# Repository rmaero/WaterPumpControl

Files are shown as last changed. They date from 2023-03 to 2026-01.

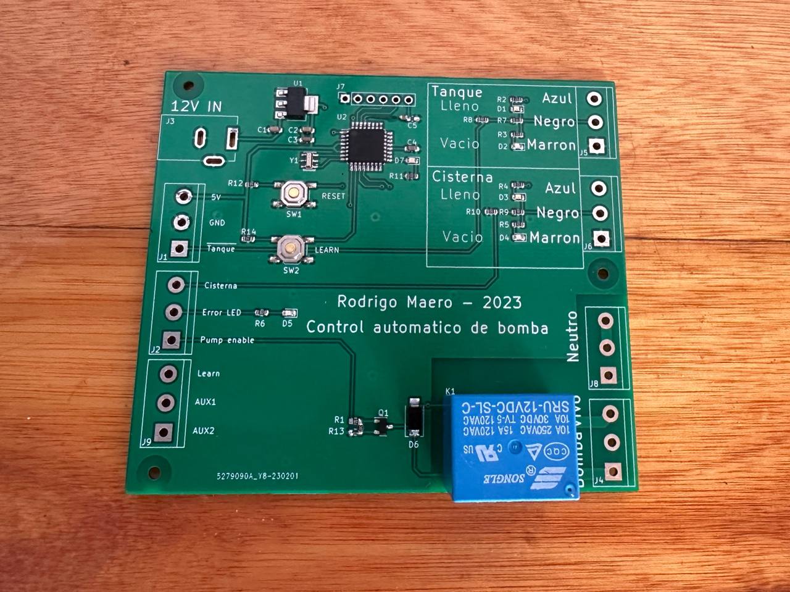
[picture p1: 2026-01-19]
Kicad/PCB_finished.jpg

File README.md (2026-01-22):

Water Pump Controller
Sistema de control automático para bombas de agua en instalaciones residenciales con cisterna y tanque elevado. Diseñado para optimizar el consumo energético y prevenir funcionamiento en seco de la bomba. La version mas actual del firmware es "MEF_IF_EEPROM".



Video demostracion
https://youtu.be/jwLdcLJ9unM

Sistema en producción implementado desde 2023

Estado: En Producción
Operando continuamente desde 2023 sin fallas en instalación residencial real.
REV. B: corregido invertidos pines Rx y Tx, resistencia pulldown de Q1. Agregado conector J10 para programar bootloader (no implementado todavia).

Problema que Resuelve
En sistemas tradicionales de cisterna + tanque elevado, las bombas funcionan con controles manuales, niveles flotantes o temporizadores simples, lo que genera:

Riesgo de funcionamiento en seco (daño a la bomba) en caso de que un sensor falle.
Desperdicio energético (bomba funcionando innecesariamente)
Falta de monitoreo del estado del sistema

Este controlador automatiza completamente el proceso con lógica inteligente. Brinda testigos luminicos para relevar el estado del tanque y de la cisterna (muy util tambien para verificar si los sensores estan funcionando correctamente en caso de aviso de falla).

Características
Hardware

Diseño de PCB custom con microcontrolador ATmega328.
Sensores de nivel de agua en cisterna y tanque
Relé para control de bomba (220V/15A)
Protección contra funcionamiento en seco
Indicadores LED de estado
Posibilidad de usar la placa como standalone sin microcontrolador integrado, sino conectandolo atraves de pines provistos en el etremo izquierdo. Facilidad para usar un ESP32 por ejemplo.

Firmware

Lógica de histéresis para evitar ciclos cortos
Protección multi-nivel:

Detección de cisterna vacía
Timeout de seguridad

Funcionamiento
Lógica básica:

Sensor detecta nivel bajo en tanque y nivel alto en cisterna → activa bomba
Sensor verifica nivel suficiente en cisterna
Bomba llena tanque hasta nivel alto
Sistema entra en standby hasta próximo ciclo

Proteccion contra funcionamiento en seco:
Por defecto, dado el caso para el que se diseñó este circuito, el tanque tiene una capacidad muy superior a la cisterna y la bomba es capaz de vaciar la cisterna en 2:15 minutos. Por lo cual se implementó un timeout que si a los 3 minutos el sensor de la cisterna no está en bajo, asume que es por falla del sensor, apaga la bomba y se queda en estado de ERROR con led rojo parpadeando

Funcion LEARN:
se puede programar que el sistema aprenda de forma automatica cuanto tiempo demora en vaciarse la cisterna. Para esto se debe tener el tanque completamente vacio y la cisterna completamente llena. Con la placa desenergizada, mantener apretado el pulsador "LEARN" y energizar la placa. Una vez que se haya encendido la bomba se puede soltar el pulsador. En este estado el microcontrolador contará el tiempo que demore en vaciarse la cisterna y lo guardará en memoria no volatil (por lo que se puede reiniciar o apagar sin problemas, el tiempo queda guardado). Asi podremos usar la proteccion contra funcionamiento en seco de forma adecuada sin necesidad de cronometrar y reprogramar el micrcocontrolador.

Especificaciones Técnicas

Microcontrolador      ATmega328
Sensores              Tipo: flotantes
Relé                  220V 15A
Alimentación          12V DC 1A
PCB                   2 capas. Dimensiones: 100mm x 80mm. 

Galería
PCB Diseñado

Instalación Real


Requisitos de Hardware

Fuente de alimentación 12V 1A
Sensores de nivel tipo flotante de 3 cables.
Cableado eléctrico certificado para bomba.

Instalación

Montar sensores en cisterna y tanque. Ajustar niveles de la misma forma que en un sistema normal.
Conectar los 3 cables de cada sensor a su correspondiente borne en la PCB.
Verificar alimentando la PCB que las luces testigo esten correctas simulando sobre los sensores manualmente que esta "lleno" o "vacio".
Conectar bomba al relé del controlador.
Alimentar el sistema.
De ser necesario, realizar la rutina de entrenamiento LEARN para calcular y calibrar el tiempo de vaciado de la cisterna.

Resultados en Producción
Desde Marzo 2023:

-Cero fallas de hardware
-Cero activaciones de funcionamiento en seco

Desarrollo Futuro (Versión Comercial)
Mejoras planificadas para siguiente versión de producto:

 Conectividad WiFi para monitoreo remoto
 App móvil para visualización de estado
 Data logging de consumo y ciclos
 Múltiples perfiles de configuración
 Carcasa plástica para montaje industrial
 Certificación eléctrica

 Consideraciones de Seguridad
⚠️ ADVERTENCIA: Este sistema maneja voltaje de red (220V). 

La instalación debe ser realizada por electricista 
Cumplir normativa eléctrica local
Incluir protección térmica en línea de bomba

Licencia
GPL V3

✉️ Contacto
Rodrigo Maero - r.maero@gmail.com
Proyecto personal desarrollado en Rosario, Argentina.

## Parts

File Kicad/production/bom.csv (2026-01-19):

Designator | Footprint | Quantity | Value | LCSC Part #
C1 | 0603 | 1 | 10uF 16V
C2 | 0603 | 1 | 10uF 16V
C3 | 0603 | 1 | 0.1uF 6.3V
C4 | 0603 | 1 | 0.1uF 6.3V
C5 | 0603 | 1 | 0.1uF 6.3V
D1 | 0603 | 1 | LED Green 0603
D2 | 0603 | 1 | LED Red 0603
D3 | 0603 | 1 | LED Green 0603
D4 | 0603 | 1 | LED Red 0603
D5 | 0603 | 1 | LED Red 0603
D6 | D_SMA | 1 | DIODE SS54 SMA
D7 | 0603 | 1 | LED Yellow
H1, H2, H3 | MountingHole_3.2mm_M3 | 3 | MountingHole
J1, J2, J4, J5, J6, J8, J9 | TerminalBlock_bornier-3_P5.08mm | 7 | Screw_Terminal_01x03
J3 | BarrelJack_Kycon_KLDX-0202-xC_Horizontal | 1 | Barrel_Jack_Switch
J7 | PinSocket_1x06_P2.54mm_Vertical | 1 | Conn_01x06_Male
JP1, JP2, JP3, JP4, JP5, JP6, JP7 | SolderJumper-2_P1.3mm_Bridged2Bar_RoundedPad1.0x1.5mm | 7 | Jumper_2_Bridged
K1 | Relay_SPDT_Finder_36.11 | 1 | 12VDC SPDT RELAY SRU-12VDC-SL-C
Q1 | SOT-23 | 1 | 2N7002
R1 | 0603 | 1 | 1k
R10 | 0603 | 1 | 1M
R11 | 0603 | 1 | 330
R12 | 0603 | 1 | 10k
R13 | 0603 | 1 | 10k
R14 | 0603 | 1 | 10k
R2 | 0603 | 1 | 470
R3 | 0603 | 1 | 470
R4 | 0603 | 1 | 470
R5 | 0603 | 1 | 470
R6 | 0603 | 1 | 330
R7 | 0603 | 1 | 1.5M
R8 | 0603 | 1 | 1M
R9 | 0603 | 1 | 1.5M
SW1, SW2 | SW_SPST_TL3342 | 2 | SW_SPST
U1 | SOT-223-3_TabPin2 | 1 | AMS1117-5.0
U2 | TQFP-32_7x7mm_P0.8mm | 1 | ATmega328P-A
Y1 | Resonator_SMD_Murata_CSTxExxV-3Pin_3.0x1.1mm_HandSoldering | 1 | Crystal 16 MHz SMD

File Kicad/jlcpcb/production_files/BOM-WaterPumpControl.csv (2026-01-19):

Comment | Designator | Footprint | LCSC
2N7002H | Q1 | SOT-23
Screw_Terminal_01x03 | J4 | TerminalBlock_bornier-3_P5.08mm
LED Red 0603 | D5 | LED_0603_1608Metric
LED Red 0603 | D2 | LED_0603_1608Metric
1k | R1 | R_0603_1608Metric
LED Green 0603 | D3 | LED_0603_1608Metric
470 | R3 | R_0603_1608Metric
10uF 16V | C1 | C_0603_1608Metric_Pad1.08x0.95mm_HandSolder
AP1117-50 | U1 | SOT-223-3_TabPin2
Screw_Terminal_01x03 | J5 | TerminalBlock_bornier-3_P5.08mm
Barrel_Jack_Switch | J3 | BarrelJack_Kycon_KLDX-0202-xC_Horizontal
Screw_Terminal_01x03 | J1 | TerminalBlock_bornier-3_P5.08mm
1.5M | R7 | R_0603_1608Metric
LED Red 0603 | D4 | LED_0603_1608Metric
470 | R5 | R_0603_1608Metric
1.5M | R9 | R_0603_1608Metric
470 | R4 | R_0603_1608Metric
10uF 16V | C2 | C_0603_1608Metric_Pad1.08x0.95mm_HandSolder
LED Green 0603 | D1 | LED_0603_1608Metric
470 | R2 | R_0603_1608Metric
330 | R6 | R_0603_1608Metric
12VDC SPDT RELAY SRU-12VDC-SL-C | K1 | Relay_SPDT_Finder_36.11
Screw_Terminal_01x03 | J2 | TerminalBlock_bornier-3_P5.08mm
1M | R10 | R_0603_1608Metric
DIODE SS54 | D6 | D_1206_3216Metric
1M | R8 | R_0603_1608Metric
Screw_Terminal_01x03 | J6 | TerminalBlock_bornier-3_P5.08mm
Screw_Terminal_01x03 | J8 | TerminalBlock_bornier-3_P5.08mm
10k | R13 | R_0603_1608Metric
Crystal_GND2 | Y1 | Resonator_SMD_Murata_CSTxExxV-3Pin_3.0x1.1mm_HandSoldering
10k | R12 | R_0603_1608Metric
0.1uF 6.3V | C3 | C_0603_1608Metric_Pad1.08x0.95mm_HandSolder
330 | R11 | R_0603_1608Metric
ATmega328P-A | U2 | TQFP-32_7x7mm_P0.8mm
Conn_01x06_Male | J7 | PinSocket_1x06_P2.54mm_Vertical
0.1uF 6.3V | C5 | C_0603_1608Metric_Pad1.08x0.95mm_HandSolder
SW_SPST | SW1 | SW_SPST_B3S-1000
LED Yellow | D7 | LED_0603_1608Metric
0.1uF 6.3V | C4 | C_0603_1608Metric_Pad1.08x0.95mm_HandSolder
Jumper_2_Bridged | JP3 | SolderJumper-2_P1.3mm_Bridged2Bar_RoundedPad1.0x1.5mm
Jumper_2_Bridged | JP2 | SolderJumper-2_P1.3mm_Bridged2Bar_RoundedPad1.0x1.5mm
Jumper_2_Bridged | JP1 | SolderJumper-2_P1.3mm_Bridged2Bar_RoundedPad1.0x1.5mm
Jumper_2_Bridged | JP4 | SolderJumper-2_P1.3mm_Bridged2Bar_RoundedPad1.0x1.5mm
Screw_Terminal_01x03 | J9 | TerminalBlock_bornier-3_P5.08mm
SW_SPST | SW2 | SW_SPST_B3S-1000
Jumper_2_Bridged | JP6 | SolderJumper-2_P1.3mm_Bridged2Bar_RoundedPad1.0x1.5mm
Jumper_2_Bridged | JP7 | SolderJumper-2_P1.3mm_Bridged2Bar_RoundedPad1.0x1.5mm
Jumper_2_Bridged | JP5 | SolderJumper-2_P1.3mm_Bridged2Bar_RoundedPad1.0x1.5mm

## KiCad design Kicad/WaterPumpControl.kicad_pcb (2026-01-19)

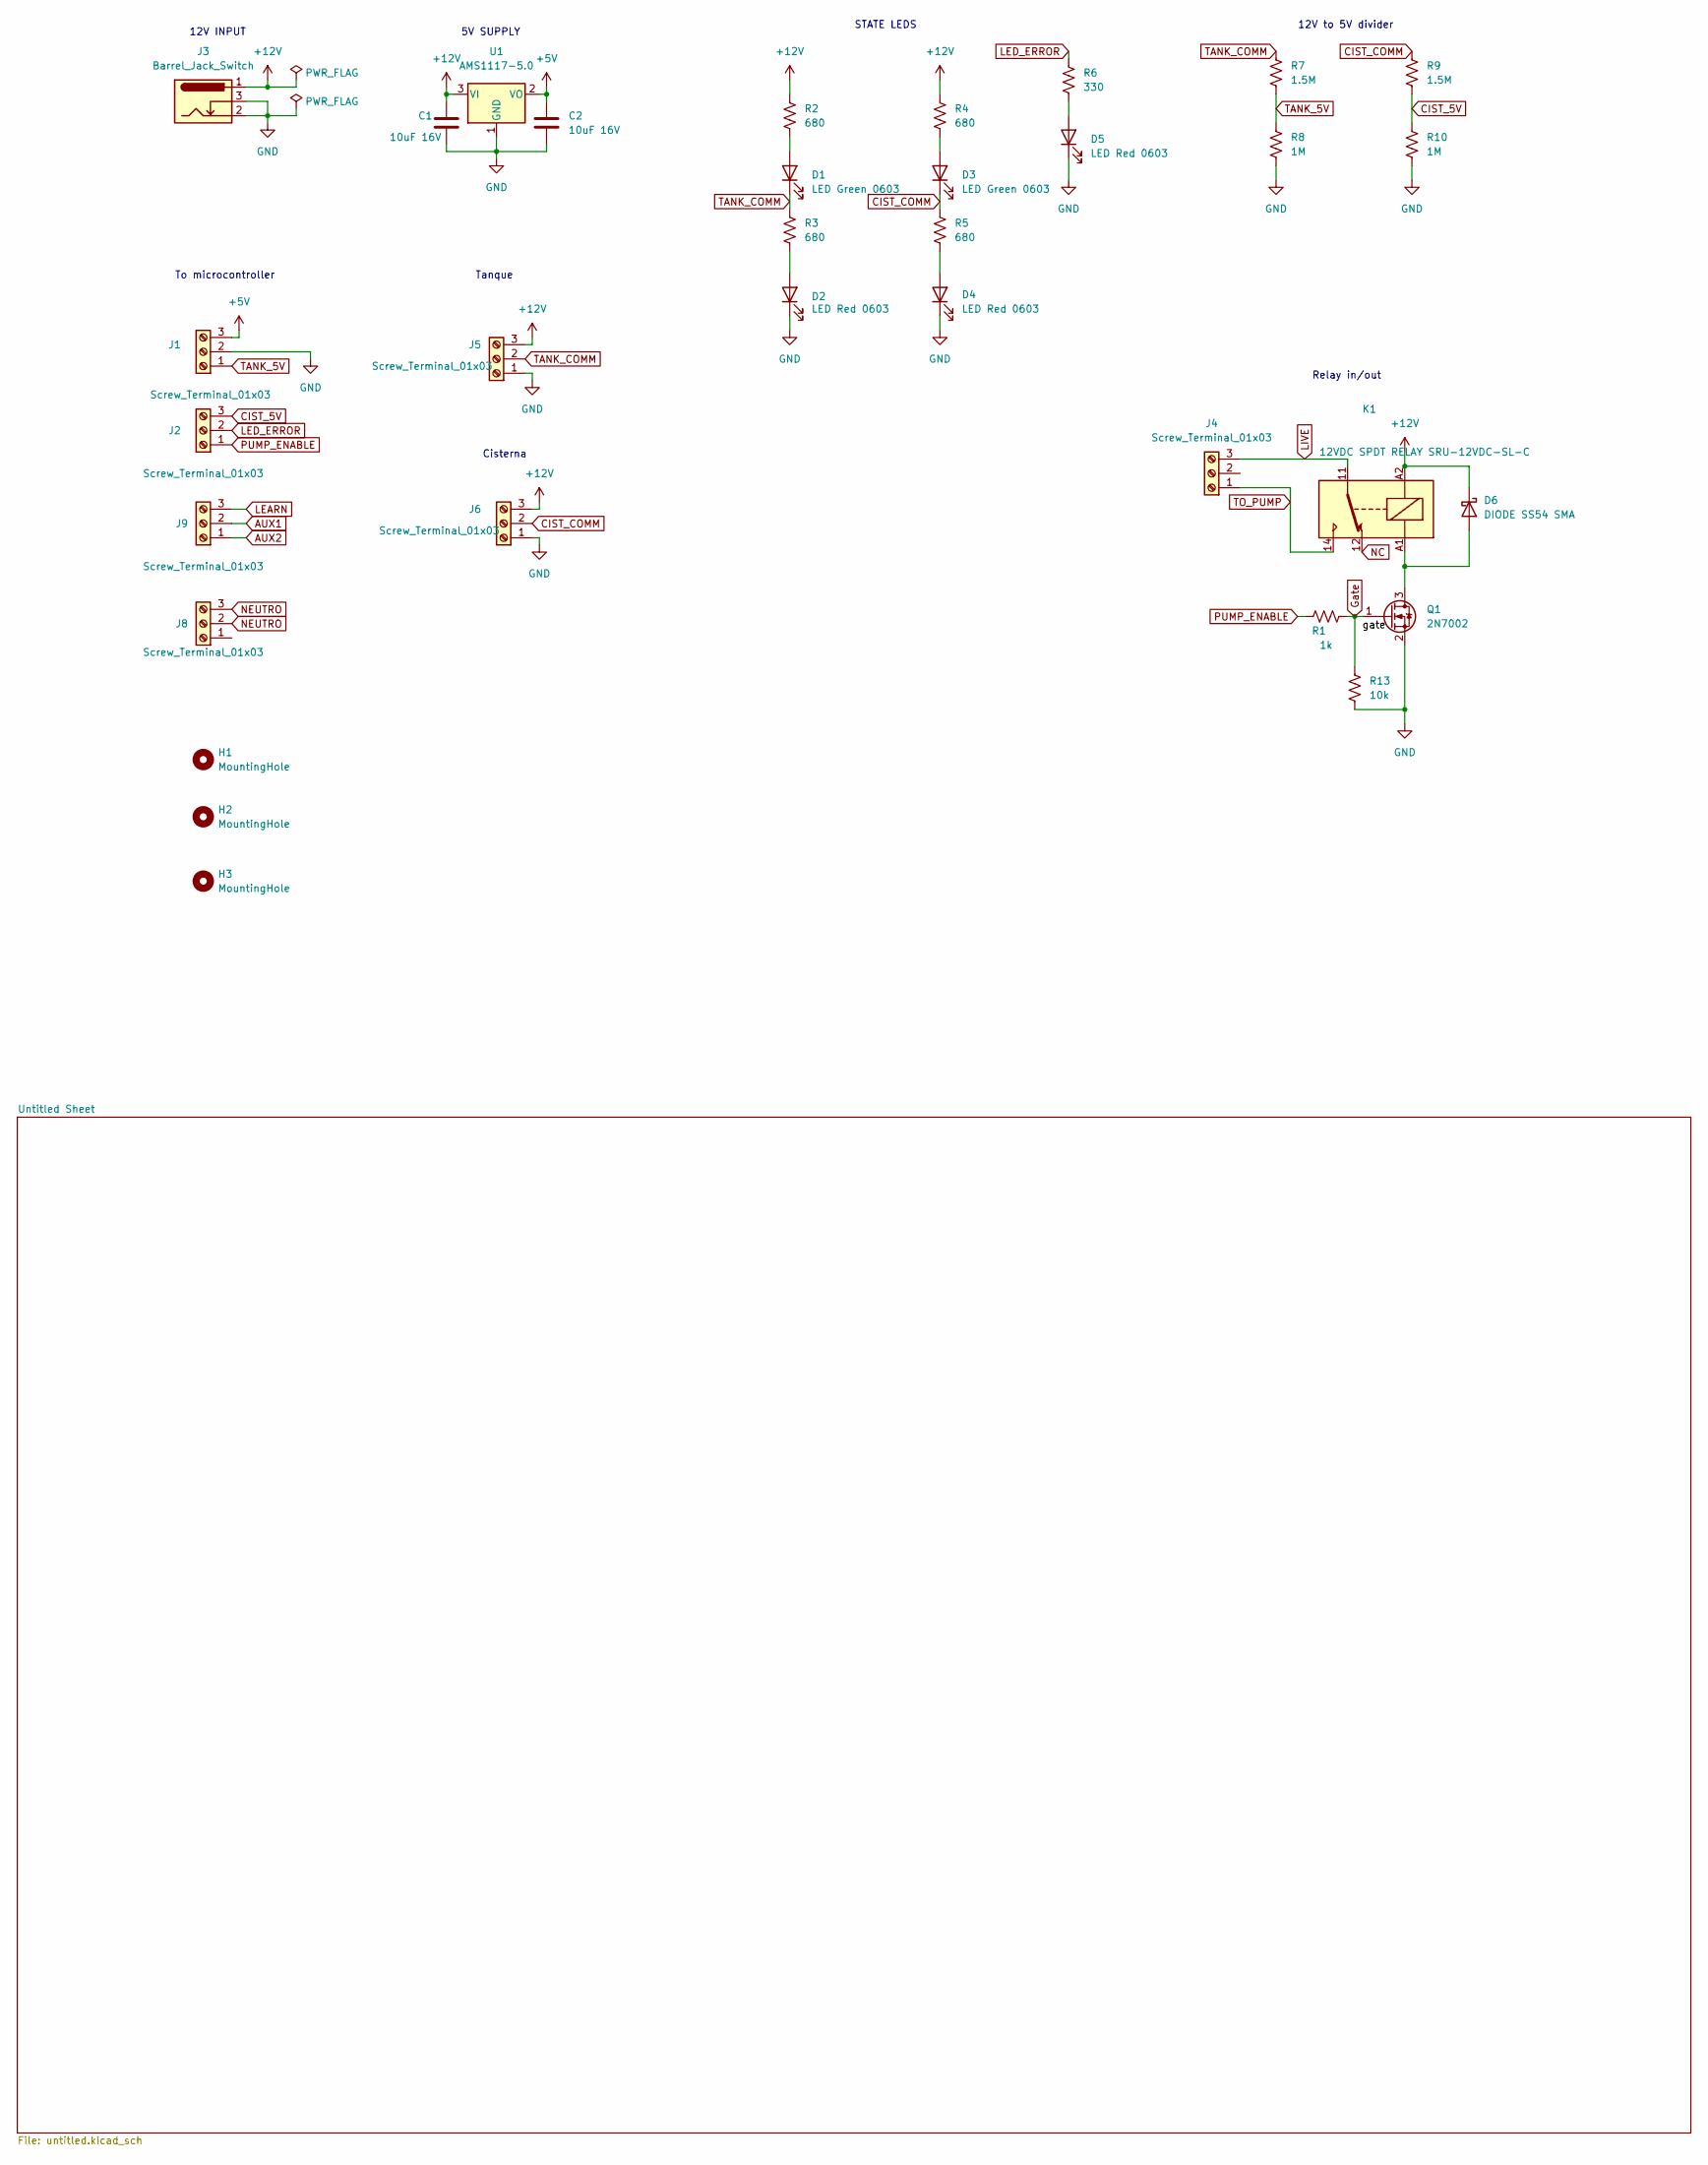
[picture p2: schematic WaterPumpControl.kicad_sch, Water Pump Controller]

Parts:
C1, C2: 10uF 16V; C_0603_1608Metric_Pad1.08x0.95mm_HandSolder
D1, D3: LED Green 0603; LED_0603_1608Metric
D2, D4, D5: LED Red 0603; LED_0603_1608Metric
D6: DIODE SS54 SMA; D_SMA
H1, H2, H3: MountingHole; MountingHole_3.2mm_M3
J1, J2, J4, J5, J6, J8, J9: Screw_Terminal_01x03; TerminalBlock_bornier-3_P5.08mm
J3: Barrel_Jack_Switch; BarrelJack_Kycon_KLDX-0202-xC_Horizontal
K1: 12VDC SPDT RELAY SRU-12VDC-SL-C; Relay_SPDT_Finder_36.11
Q1: 2N7002; SOT-23
R1: 1k; R_0603_1608Metric
R2, R3, R4, R5: 680; R_0603_1608Metric
R6: 330; R_0603_1608Metric
R7, R9: 1.5M; R_0603_1608Metric
R8, R10: 1M; R_0603_1608Metric
R13: 10k; R_0603_1608Metric
U1: AMS1117-5.0; SOT-223-3_TabPin2

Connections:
+12V: C1.1, D6.1 (K), J3.1, J5.3, J6.3, K1.A2, R2.1, R4.1, U1.3 (VI)
AUX1: J9.2; also elsewhere on the board
AUX2: J9.1; also elsewhere on the board
CIST_5V: J2.3, R9.2, R10.1; also elsewhere on the board
CIST_COMM: D3.1 (K), J6.2, R5.1, R9.1
GND: C1.2, C2.2, D2.1 (K), D4.1 (K), D5.1 (K), J1.2, J3.2, J3.3, J5.1, J6.1, Q1.2 (S), R8.2, R10.2, R13.2, U1.1 (GND); also elsewhere on the board
Gate: Q1.1 (G), R1.2, R13.1
LEARN: J9.3; also elsewhere on the board
LED_ERROR: J2.2, R6.1; also elsewhere on the board
LIVE: J4.3, K1.11
NC: K1.12
NEUTRO: J8.2, J8.3
unnamed: D1.2 (A), R2.2
unnamed: D2.2 (A), R3.2
unnamed: D3.2 (A), R4.2
unnamed: D4.2 (A), R5.2
unnamed: D5.2 (A), R6.2
unnamed: D6.2 (A), K1.A1, Q1.3 (D)
PUMP_ENABLE: J2.1, R1.1; also elsewhere on the board
TANK_5V: J1.1, R7.2, R8.1; also elsewhere on the board
TANK_COMM: D1.1 (K), J5.2, R3.1, R7.1
TO_PUMP: J4.1, K1.14
VCC: C2.1, J1.3, U1.2 (VO); also elsewhere on the board

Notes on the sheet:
Relay in/out
Cisterna
To microcontroller
Tanque
12V INPUT
12V to 5V divider
5V SUPPLY
STATE LEDS

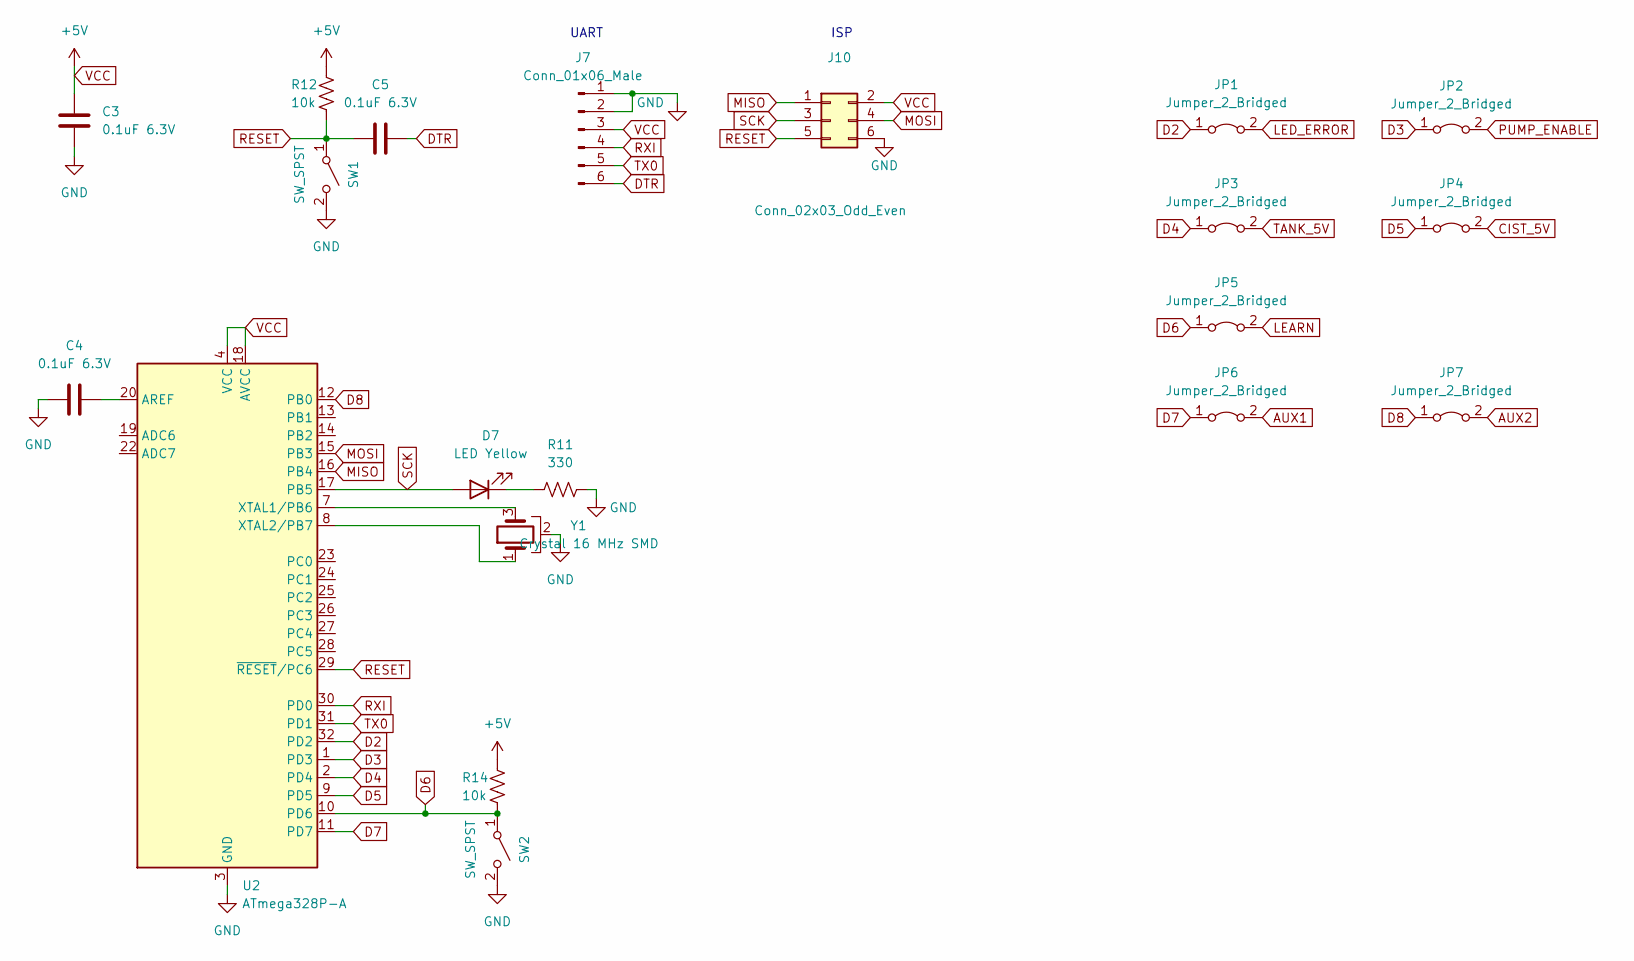
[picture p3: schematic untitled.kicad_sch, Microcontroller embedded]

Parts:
C3, C4, C5: 0.1uF 6.3V; C_0603_1608Metric_Pad1.08x0.95mm_HandSolder
D7: LED Yellow; LED_0603_1608Metric
J7: Conn_01x06_Male; PinSocket_1x06_P2.54mm_Vertical
J10: Conn_02x03_Odd_Even; PinHeader_2x03_P2.54mm_Vertical
JP1, JP2, JP3, JP4, JP5, JP6, JP7: Jumper_2_Bridged; SolderJumper-2_P1.3mm_Bridged2Bar_RoundedPad1.0x1.5mm
R11: 330; R_0603_1608Metric
R12, R14: 10k; R_0603_1608Metric
SW1, SW2: SW_SPST; SW_SPST_TL3342
U2: ATmega328P-A; TQFP-32_7x7mm_P0.8mm
Y1: Crystal 16 MHz SMD; Resonator_SMD_Murata_CSTxExxV-3Pin_3.0x1.1mm_HandSoldering

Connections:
AUX1: JP6.2 (B); also elsewhere on the board
AUX2: JP7.2 (B); also elsewhere on the board
CIST_5V: JP4.2 (B); also elsewhere on the board
D2: JP1.1 (A), U2.32 (PD2)
D3: JP2.1 (A), U2.1 (PD3)
D4: JP3.1 (A), U2.2 (PD4)
D5: JP4.1 (A), U2.9 (PD5)
D6: JP5.1 (A), R14.2, SW2.1 (A), U2.10 (PD6)
D7: JP6.1 (A), U2.11 (PD7)
D8: JP7.1 (A), U2.12 (PB0)
DTR: C5.2, J7.6
GND: C3.2, C4.1, J7.1, J7.2, J10.6, R11.2, SW1.2 (B), SW2.2 (B), U2.3 (GND), U2.5 (GND), U2.21 (GND), Y1.2; also elsewhere on the board
LEARN: JP5.2 (B); also elsewhere on the board
LED_ERROR: JP1.2 (B); also elsewhere on the board
MISO: J10.1, U2.16 (PB4)
MOSI: J10.4, U2.15 (PB3)
unnamed: C4.2, U2.20 (AREF)
unnamed: D7.1 (K), R11.1
unnamed: U2.7 (XTAL1/PB6), Y1.3
unnamed: U2.8 (XTAL2/PB7), Y1.1
PUMP_ENABLE: JP2.2 (B); also elsewhere on the board
RESET: C5.1, J10.5, R12.2, SW1.1 (A), U2.29 (~RESET/PC6)
RXI: J7.4, U2.30 (PD0)
SCK: D7.2 (A), J10.3, U2.17 (PB5)
TANK_5V: JP3.2 (B); also elsewhere on the board
TX0: J7.5, U2.31 (PD1)
VCC: C3.1, J7.3, J10.2, R12.1, R14.1, U2.4 (VCC), U2.6 (VCC), U2.18 (AVCC); also elsewhere on the board

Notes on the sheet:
ISP
UART

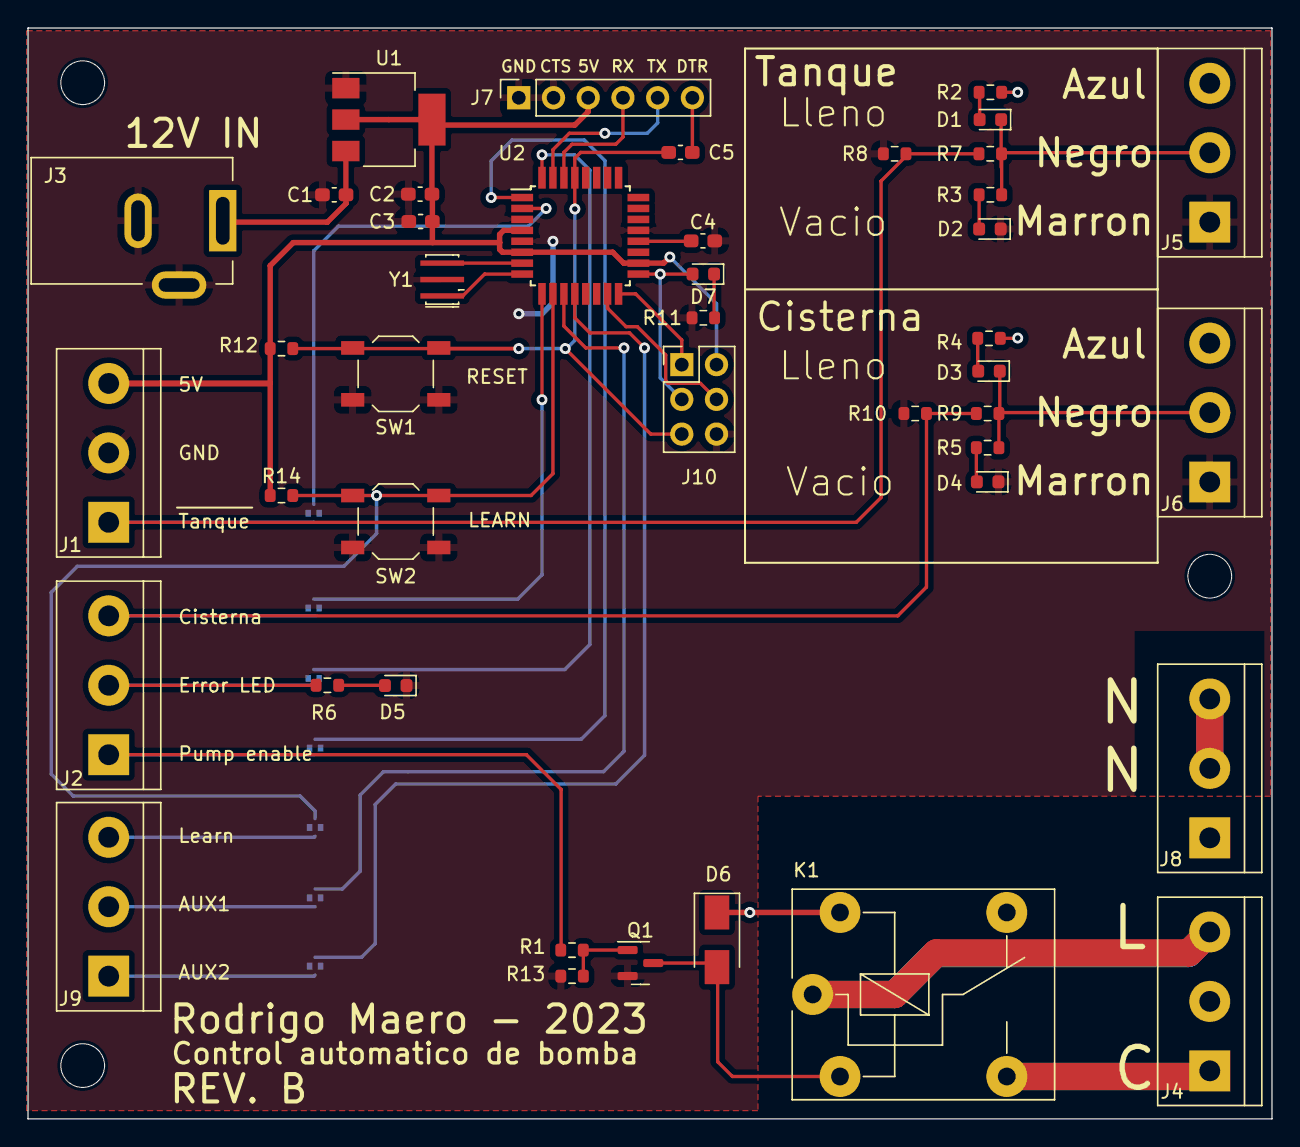
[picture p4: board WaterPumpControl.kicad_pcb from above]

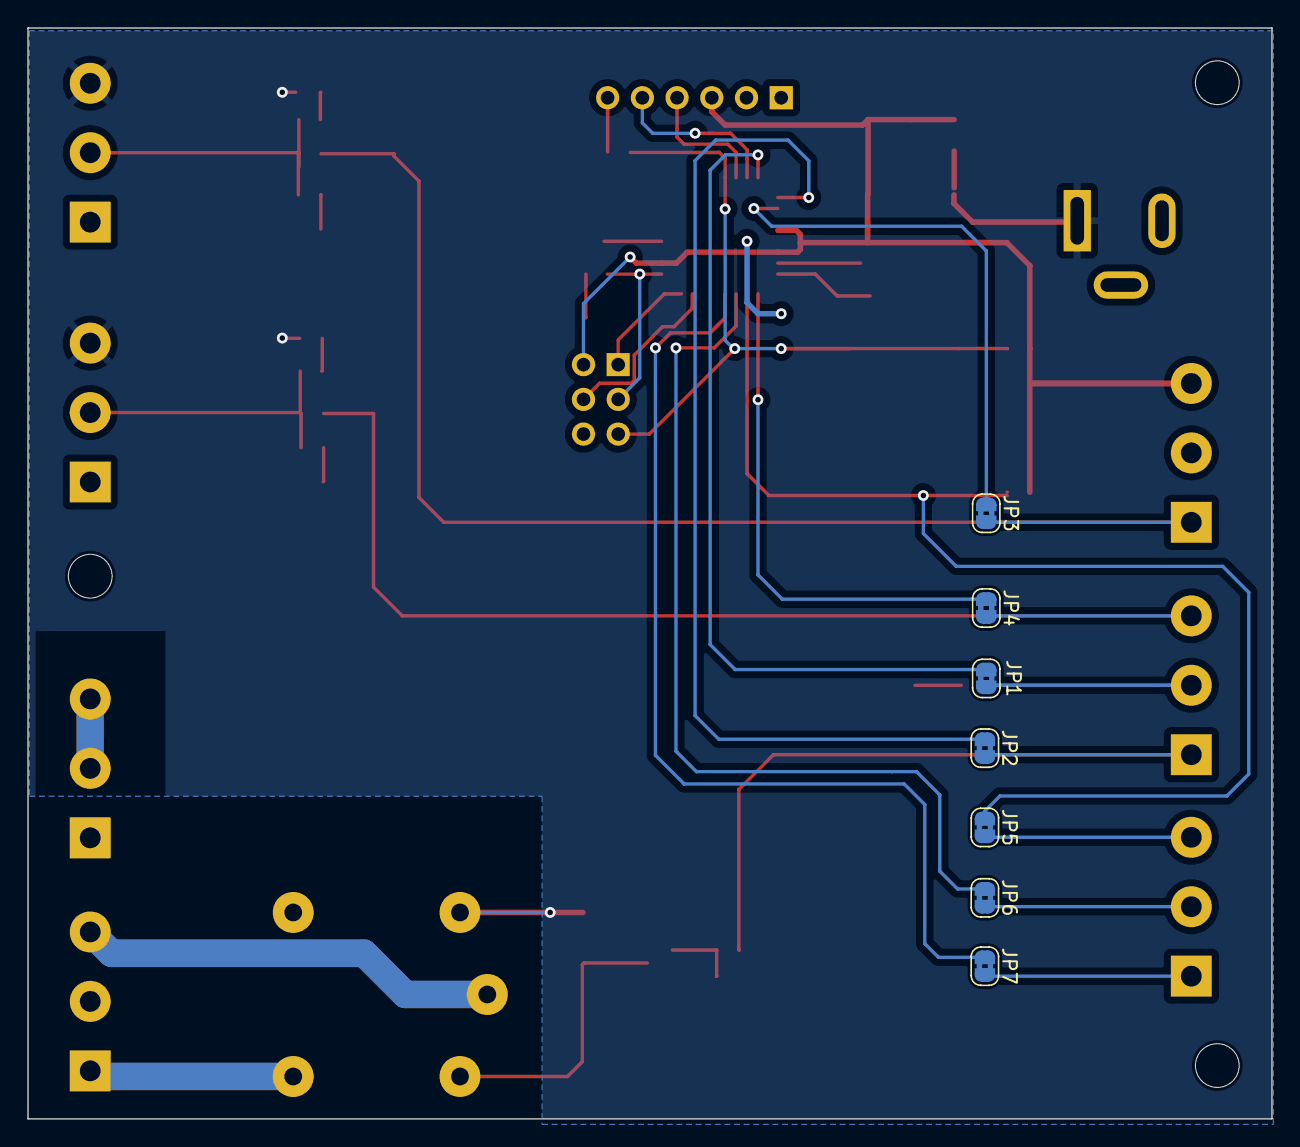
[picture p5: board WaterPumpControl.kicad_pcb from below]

Board: 2 copper layers, 91.0 x 79.8 mm, 53 parts (7 on the bottom side), 40 nets.

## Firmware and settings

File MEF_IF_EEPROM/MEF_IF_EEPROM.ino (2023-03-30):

/*---------------------------------------------------------------------------------
Rodrigo Maero 2023


---------------------------------------------------------------------------------*/


#include <EEPROM.h>

/*********************************************************************************
****************************PINS*************************************************/

#define PIN_LEARN 6
#define PIN_CISTERNA 5
#define PIN_TANQUE 4
#define PIN_BOMBA 3
#define PIN_LED_ERROR 2
#define PIN_AUX1 7
#define PIN_AUX2 8

/*************************DEFAULT TIME*****************************************/
#define TIEMPO_MAX_ON_MILLIS 180000 //3 min *60 seg * 1000 ms = 180.000 millis
#define ONE_MIN_TO_MILLIS 60000  // *60 seg * 1000 ms
#define MIN_TO_MILLIS 60000 // *60 seg * 1000 ms

/******************************************************************************
*****************************EEPROM*******************************************/
#define EEPROM_ADDRESS 0

struct Flash {
  char flag;
  uint32_t maxTimeMillis;
};

/************************************DEBUG**********************************/
#define PIN_LED_INTERNAL 13
bool ledState;

/***************************************************************************/
uint32_t maxTimeOn;
uint32_t startLearningTime;
uint32_t startPumpTime;

uint32_t currentTime;
uint32_t shortLoopTime;
uint32_t longLoopTime;


/**************************************************************************
----------------SENSOR INPUTS-----------------------------------------------
***************************************************************************/
//0V = LLENO, 5V=VACIO
bool isCisternaFull()
{
  return  !digitalRead(PIN_CISTERNA);
}

//0V = LLENO, 5V=VACIO
bool isTanqueFull()
{
  return !digitalRead(PIN_TANQUE);
}

/**************************************************************************
----------------RELAY OUTPUT-----------------------------------------------
***************************************************************************/
void turnRelayOn(bool t)
{
  digitalWrite(PIN_BOMBA,t);
//debug led  
  digitalWrite(PIN_LED_INTERNAL,t);
}


/**************************************************************************
----------------ERROR LED OUTPUT-------------------------------------------
***************************************************************************/
uint16_t ledTimer;
void blinkErrorLed()
{
  if(ledTimer==0)
    {
      ledTimer=1;
      ledState=  !ledState;
        //DEBUG 
        // digitalWrite(PIN_LED_INTERNAL,ledState);
        Serial.print("Error Led:");
        Serial.println(ledState);
    }
  digitalWrite(PIN_LED_ERROR,ledState);  
}


/**************************************************************************
----------------MAIN STATE MACHINE-----------------------------------------
***************************************************************************/
typedef enum States {WAITING, LEARNING, PUMP_ON, SM_ERROR};
States relayStateMachine;

void stateMachine()
{
//SWITCH-CASE ANDA MAL EN ARDUINO, REEMPLAZO POR IF
  if(relayStateMachine==WAITING)
  {
      if( isCisternaFull()  &&  !isTanqueFull())
      {        
        relayStateMachine = PUMP_ON;          
        startPumpTime=millis();        
        turnRelayOn(true);        
          //DEBUG
          Serial.print("Estado:");
          Serial.println(relayStateMachine);
          Serial.println("ENCIENDO BOMBA");
      } 
  }else if(relayStateMachine==LEARNING)
  {
      //Serial.println("LEARNING");
      turnRelayOn(true);
      if(!isCisternaFull()  ||  isTanqueFull())
      {
        Serial.println("Terminado ciclo learning");
        turnRelayOn(false);
        maxTimeOn=millis()-startLearningTime + ONE_MIN_TO_MILLIS;//maxTimeOn = tiempo medido + 1 min
        Serial.print("TIEMPO MAX PRENDIDO:");        
        Serial.println(maxTimeOn);
        /*********SAVE TO EEPROM*****************************************************/
        Flash saveToEEPROM;
        saveToEEPROM.flag='S';
        saveToEEPROM.maxTimeMillis=maxTimeOn;
        
        EEPROM.put(EEPROM_ADDRESS,saveToEEPROM);
        EEPROM.get(EEPROM_ADDRESS,saveToEEPROM);
        
        Serial.print("Tiempo max guardado en EEPROM:");        
        Serial.println(saveToEEPROM.maxTimeMillis);
        Serial.print("Guardado (S= SAVED, N=NOT saved):");
        Serial.println(saveToEEPROM.flag);
        /**************************************************************************/
        relayStateMachine = WAITING;
        Serial.println("Estado: WAITING");
      }
  }else if(relayStateMachine == PUMP_ON)
  { 
      turnRelayOn(true);
      if( !isCisternaFull()  || isTanqueFull()  )
      {
        Serial.println("Bomba apagada\nEstado: WAITING");
        turnRelayOn(false);
        relayStateMachine = WAITING;
      }
      unsigned long elapsedTime = millis()-startPumpTime;
      
      Serial.print("Quedan ");
      Serial.print((maxTimeOn-elapsedTime)/1000);
      Serial.println(" segundos hasta error");

      if(elapsedTime >= maxTimeOn)
      {
        Serial.print("Pasaron:"); 
        Serial.print(elapsedTime);                 
        Serial.println("ms"); 
        Serial.println("Bomba apagada\nEstado: ERROR");
        relayStateMachine = SM_ERROR;   
        ledTimer=1;      
        turnRelayOn(false);
      }
  }else if(relayStateMachine==SM_ERROR)
  {   
      blinkErrorLed();
  }else{
      relayStateMachine=WAITING;
  }
}


/**************************************************************************
--------------------------------INIT---------------------------------------
***************************************************************************/
void setup() {
  Serial.begin(9600);
   while (!Serial) {
    ; // wait for serial port to connect. Needed for native USB port only
  }
//debug 
  pinMode(PIN_LED_INTERNAL, OUTPUT);
    
// BOTON LEARN
  pinMode(PIN_LEARN, INPUT_PULLUP);
  
//SENSORES CISTERNA Y TANQUE //DEBUG WITH BUTTONS: PULLUP
  pinMode(PIN_TANQUE, INPUT);
  pinMode(PIN_CISTERNA, INPUT);

//PINES SALIDA LED Y BOMBA  
  pinMode(PIN_LED_ERROR, OUTPUT);
  pinMode(PIN_BOMBA, OUTPUT);


//SET INITIAL STATE 
  if(digitalRead(PIN_LEARN)==0) //si boton LEARN presionado durante el inicio
  {
    delay(1000);
    if(digitalRead(PIN_LEARN)==0 ) //si sigue presionado 1 seg despues
    {
      if( !isTanqueFull() && isCisternaFull()){ //si esta en el estado correcto (cist llena, tanque vacio)
        relayStateMachine=LEARNING;
      }else{
        relayStateMachine=SM_ERROR;
      }
    }
  }else{
    relayStateMachine=WAITING;
    Flash readFromEEPROM;
    EEPROM.get(EEPROM_ADDRESS,readFromEEPROM);
    
    Serial.print("Tiempo max guardado en EEPROM:");
    Serial.println(readFromEEPROM.maxTimeMillis);
    Serial.print("Guardado (S= SAVED, N=NOT saved):");
    Serial.println(readFromEEPROM.flag);

    if(readFromEEPROM.flag=='S')
    {
      maxTimeOn = readFromEEPROM.maxTimeMillis;
      Serial.print("Tomo tiempo guardado en EEPROM (ms):");
      Serial.println(maxTimeOn);
    }else{
      maxTimeOn = TIEMPO_MAX_ON_MILLIS; 
      Serial.print("Tomo tiempo default:");
      Serial.println(maxTimeOn);
      Serial.println("Estado: WAITING");
    }
  }
  ledTimer=1;
  ledState=0;
  longLoopTime =millis();  
  shortLoopTime=millis();
}

/**************************************************************************
--------------------------------MAIN LOOP----------------------------------
***************************************************************************/
void loop() {
  stateMachine();
  currentTime = millis();  
  /*every 50ms
  if( (currentTime-shortLoopTime) >=50 )
  {
    shortLoopTime = currentTime;
    
  }
  */
  //every 1000ms 
  if( (currentTime-longLoopTime) >=1000)  
  {
    longLoopTime = currentTime;
    if(ledTimer)
    {
      ledTimer--;
    }
  }
}

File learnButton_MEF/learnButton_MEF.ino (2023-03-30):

#include <EEPROM.h>

#define PIN_LEARN 4
#define PIN_CISTERNA 5
#define PIN_TANQUE 6
#define PIN_BOMBA 7
#define PIN_LED_ERROR 8
#define TIEMPO_MAX_ON_MILLIS 5000//180000 //3 min *60 seg * 1000 ms = 180.000 millis
#define MIN_TO_MILLIS 60000 // *60 seg * 1000 ms

//debug
#define PIN_LED_INTERNAL 13
bool ledState;

uint32_t maxTimeOn;
uint32_t startLearningTime;
uint32_t startPumpTime;

uint32_t currentTime;
uint32_t shortLoopTime;
uint32_t longLoopTime;


/**************************************************************************
----------------SENSOR INPUTS-----------------------------------------------
***************************************************************************/
//0V = VACIO, 5V=LLENO
bool isCisternaFull()
{
  return  digitalRead(PIN_CISTERNA);
}

//0V = VACIO, 5V=LLENO
bool isTanqueFull()
{
  return digitalRead(PIN_TANQUE);
}

/**************************************************************************
----------------RELAY OUTPUT-----------------------------------------------
***************************************************************************/
void turnRelayOn(bool t)
{
  digitalWrite(PIN_BOMBA,t);
//debug button  
  digitalWrite(PIN_LED_INTERNAL,t);
Serial.print("Bomba:");
Serial.println(t);
}


/**************************************************************************
----------------ERROR LED OUTPUT-------------------------------------------
***************************************************************************/
uint16_t ledTimer;
void blinkErrorLed()
{
  if(ledTimer==0)
    {
      ledTimer=1;
      ledState=  !ledState;
    }
  digitalWrite(PIN_LED_ERROR,ledState);

  //DEBUG 
   digitalWrite(PIN_LED_INTERNAL,ledState);
  Serial.print("Error Led:");
  Serial.println(ledState);

}


/**************************************************************************
----------------MAIN STATE MACHINE-----------------------------------------
***************************************************************************/

typedef enum States {WAITING, LEARNING, PUMP_ON, SM_ERROR};
States relayStateMachine;

void stateMachine()
{
/*-------DEBUG-------*/
if(relayStateMachine == SM_ERROR)
{
  Serial.println("IT IS IN ERROR STATE");  
  //blinkErrorLed();
}
/*-------------END DEBUG------*/
Serial.print("Estado:");
Serial.println(relayStateMachine);

  switch(relayStateMachine)    
  {
    case WAITING:

      if( isCisternaFull()  &&  !isTanqueFull())
      {
        relayStateMachine = PUMP_ON;          
        startPumpTime=millis();        
        turnRelayOn(true);        
      }   
      /* LEARN BUTTON
      if(key_getPressEv())
      {
        relayStateMachine = LEARNING;
        startLearningTime = millis();
        turnRelayOn(true);
      } 
      */           
    break;

    case LEARNING:
      Serial.println("LEARNING");
      turnRelayOn(true);
      if(!isCisternaFull()  ||  isTanqueFull())
      {
        turnRelayOn(false);
        maxTimeOn=millis()-startLearningTime;
        Serial.print("TIEMPO MAX PRENDIDO:");        
        Serial.println(maxTimeOn);
        //TODO: SAVE TO EEPROM
        relayStateMachine = WAITING;
      }
    break;
    
    case PUMP_ON:  
      turnRelayOn(true);
      if( !isCisternaFull()  || isTanqueFull()  )
      {
        turnRelayOn(false);
        relayStateMachine = WAITING;
      }
      unsigned long elapsedTime = millis()-startPumpTime;
      
      Serial.print("Quedan ");
      Serial.print((maxTimeOn-elapsedTime)/1000);
      Serial.println(" segundos hasta error");

      if(elapsedTime >= maxTimeOn)
      {
        Serial.print("Pasaron:"); 
        Serial.print(elapsedTime);                 
        Serial.println("ms"); 
        Serial.println("paso estado a ERROR"); 
        relayStateMachine = SM_ERROR;   
        ledTimer=1;      
        turnRelayOn(false);
      }
    break;
    
    case SM_ERROR:     
      Serial.println("ERROR"); 
      blinkErrorLed();
    break;

    default:
      relayStateMachine=WAITING;  
    break;  
  }
}

/**************************************************************************
----------------STATE MACHINE FOR LEARN BUTTON-----------------------------
***************************************************************************/
/*
  typedef enum ButtonStates {WAITING_ACTIVATION,WAITING_DEACTIVATION};
  ButtonStates learnStateMachine;
  
  bool eventSw=0;
  
  uint16_t learnTimer =0;

  void checkLearnButton()
  {
    switch(learnStateMachine)
    {      
      case WAITING_ACTIVATION:
        if(digitalRead(PIN_LEARN)==0)
        {
          learnTimer=3; //wait 3 secs 
          learnStateMachine = WAITING_DEACTIVATION;
        }
      break;
      
      case WAITING_DEACTIVATION:
        if(digitalRead(PIN_LEARN))
        {          
          learnTimer=0;
          eventSw = 0;
          learnStateMachine = WAITING_ACTIVATION;
        }
        if(digitalRead(PIN_LEARN)==0 && learnTimer<=0)
        {
          eventSw = 1;
        }
      break;
      
      default:
        learnStateMachine = WAITING_ACTIVATION;
        eventSw=0;
      break;
    }
  }
  //check for key press events, event = 1 when button pressed
  bool key_getPressEv()
  {
    bool ret =0;
    if(eventSw)
    {
      eventSw = 0;
      ret=1;
    }
    return ret;
  }
*/

/**************************************************************************
--------------------------------INIT---------------------------------------
***************************************************************************/
void setup() {

//debug 
  pinMode(PIN_LED_INTERNAL, OUTPUT);
  Serial.begin(9600);
  
// BOTON LEARN
  pinMode(PIN_LEARN, INPUT_PULLUP);
  
//SENSORES CISTERNA Y TANQUE //DEBUG: PULLUP
  pinMode(PIN_TANQUE, INPUT_PULLUP);
  pinMode(PIN_CISTERNA, INPUT_PULLUP);

//PINES SALIDA LED Y BOMBA  
  pinMode(PIN_LED_ERROR, OUTPUT);
  pinMode(PIN_BOMBA, OUTPUT);


//SET INITIAL STATE 
  if(digitalRead(PIN_LEARN)==0) //si boton LEARN apretado durante el inicio
  {
    delay(20);
    relayStateMachine=LEARNING;
  }else{
    relayStateMachine=WAITING;
    maxTimeOn = TIEMPO_MAX_ON_MILLIS; //TODO: CHOOSE BETWEEN LEARN AND DEFAULT
  }
  
  ledTimer=1;
  ledState=0;
  longLoopTime =millis();  
  shortLoopTime=millis();
}


/**************************************************************************
--------------------------------MAIN LOOP----------------------------------
***************************************************************************/
void loop() {
  //checkLearnButton();
  currentTime = millis();  
  stateMachine();
  /*every 50ms
  if( (currentTime-shortLoopTime) >=50 )
  {
    shortLoopTime = currentTime;
    
  }
  */
  //every 1000ms 
  if( (currentTime-longLoopTime) >=1000)  
  {
    longLoopTime = currentTime;
    /*
    if(learnTimer)    
    {
      learnTimer--;
    }
    */
    if(ledTimer)
    {
      ledTimer--;
    }
  }
  
}

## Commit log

2023-03-30 Commit inicial. MEF_IF uses if-else instead of switch-case
2023-03-30 Rutina para guardar en FLASH corregida. Limpieza de mensajes de puerto serie para debug
2026-01-19 Commit inicial de proyecto kicad. Rev B. corregidos pines RX y TX, corregido resistencia pulldown de Q1. Agregado puerto de programacion ICSP para grabar bootloader (no testeado).
    [BOM-WaterPumpControl.csv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]
